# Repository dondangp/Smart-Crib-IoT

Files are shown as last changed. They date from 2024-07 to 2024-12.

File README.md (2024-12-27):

# Smart Crib IoT Abstract

The Smart Crib project integrates hardware and software components to provide users with a seamless and efficient smart home management solution. The system features smart lights, a smart door lock, and a smart fan, all of which can be controlled remotely through a user-friendly mobile application. The application serves as the central interface, allowing users to adjust light brightness, lock and unlock doors via a keypad or app controls, and set fan speeds. Communication between the app and devices is facilitated through an Azure Virtual Machine (VM) server, which processes HTTP control commands and maintains device statuses in real time.

The hardware layer includes an ESP32 microcontroller for the smart door lock & light and a Raspberry Pi Pico for the smart fan, enabling autonomous operations and network communication. The smart door lock features a keypad for local passcode input, providing an additional layer of security. The smart fan allows speed adjustments for customized comfort, while the smart lights support dynamic brightness levels for personalized lighting. By leveraging cloud-based infrastructure and efficient task management on microcontrollers, the Smart Crib project ensures reliable, responsive, and secure smart home control, blending convenience with cutting-edge IoT technology.

# Contributors
-  **Don Dang (Project Lead)**: Created the Smart Home React Native App and Final Poster. Scheduled meetings and assigned tasks for each individual and monitored who completed tasks and attended meetings.
-  **Luis Del Rio**: Created Azure VM server, Smart Light and Smart Doorlock devices. 
-  **Zait Martinez**: Created the hardware, software development, and Printed Circuit Board (PCB) for Smart Fan
- **Ethan Debnath**: Developed Software for IoT App
- **Pranav Pujar**: Developed Software for IoT App

*As of December 03, 2024 - This project will be wrapping up to a finish for Demo Day with no more commits to be made.*

## Features

- **Smart Lights**: Set the brightness of connected smart lights (0-100). Motion detection when someone walks nearby it will turn on the lights.
- **Smart Door Lock**: Lock or unlock the smart door with a simple toggle (Lock/Unlock). Keypad integration to unlock/lock the door lock.
- **Smart Fan**: Adjust the fan speed (Off, Cool, or Heat) to suit your comfort. Has a thermostat attached to it to indicate the degree in fahrenheit and also red and blue LED which will turn on to detect cool or heat mode of the fan.
- **Settings**: Settings to change the Smart Door Lock password.

## Built With

- **React Native**: A popular framework for building mobile applications using React.
- **Axios**: For making HTTP requests to the server.
- **@react-navigation**: For implementing tab-based navigation.
- **@expo/vector-icons**: For using Ionicons in the application.
- **ESP-32**: Smart light & lock hardware/software development
- **Raspberry Pi Pico**: Smart Fan & hardware/software development

# Prerequisites

Before you begin, ensure the following tools and dependencies are installed:

### 1. **Node.js**
   - Install Node.js to manage JavaScript runtime and packages.  
   [Download Node.js](https://nodejs.org/)

### 2. **Xcode**
   - Required for running React Native on iOS devices or emulators.  
   [Download Xcode](https://developer.apple.com/xcode/)

### 3. **npm or yarn**
   - Package managers installed along with Node.js for managing dependencies.

### 4. **Expo CLI**
   - To run the React Native application on mobile devices or emulators. Install via:
     ```bash
     npm install -g expo-cli
     ```

### 5. **Dependencies**
   - Install necessary packages:
     ```bash
     npm install
     npm install axios
     npx expo install expo@latest
     npx expo install --fix
     ```

### 6. **Network Requirement**
   - **Note**: UTA WiFi blocks React Native Expo. Use an alternative WiFi connection.

### 7. **C and Python 3.12.0+**
   - Ensure you have C Version C23 and Python 3.12.0 or higher installed for additional scripts or integrations.

## App Video Demos
[Smart Light & Lock Demo](https://www.youtube.com/watch?v=xLqYLixEVfE)

[Smart Fan Demo](https://www.youtube.com/shorts/cb8d_wNGdIk)

[Final Demo](https://youtu.be/l44uO0imUA0?si=sPAH7cayEWo_ZzFX)

## Demo Images
### Smart Fan Printed Circuit Board
Smart Fan Printed Circuit Board
### Smart Fan
smartfan
### Smart Door Lock Front
doorlock_front
### Smart Door Lock Keypad
doorlock_keypad
### Smart Light (Off)
smart_light_off
### Smart Light (On)
smart_light_on
### Smart Fan Final Printed Circuit Board
smart_fan_pcb

### Smart Fan Back Layout
smart_fan_pcb

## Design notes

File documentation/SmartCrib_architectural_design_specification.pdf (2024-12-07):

## DEPARTMENT OF COMPUTER SCIENCE & ENGINEERING THE

## UNIVERSITY OF TEXAS AT ARLINGTON

## ARCHITECTURAL DESIGN SPECIFICATION CSE

## 4316: SENIOR DESIGN I

# SUMMER 2024

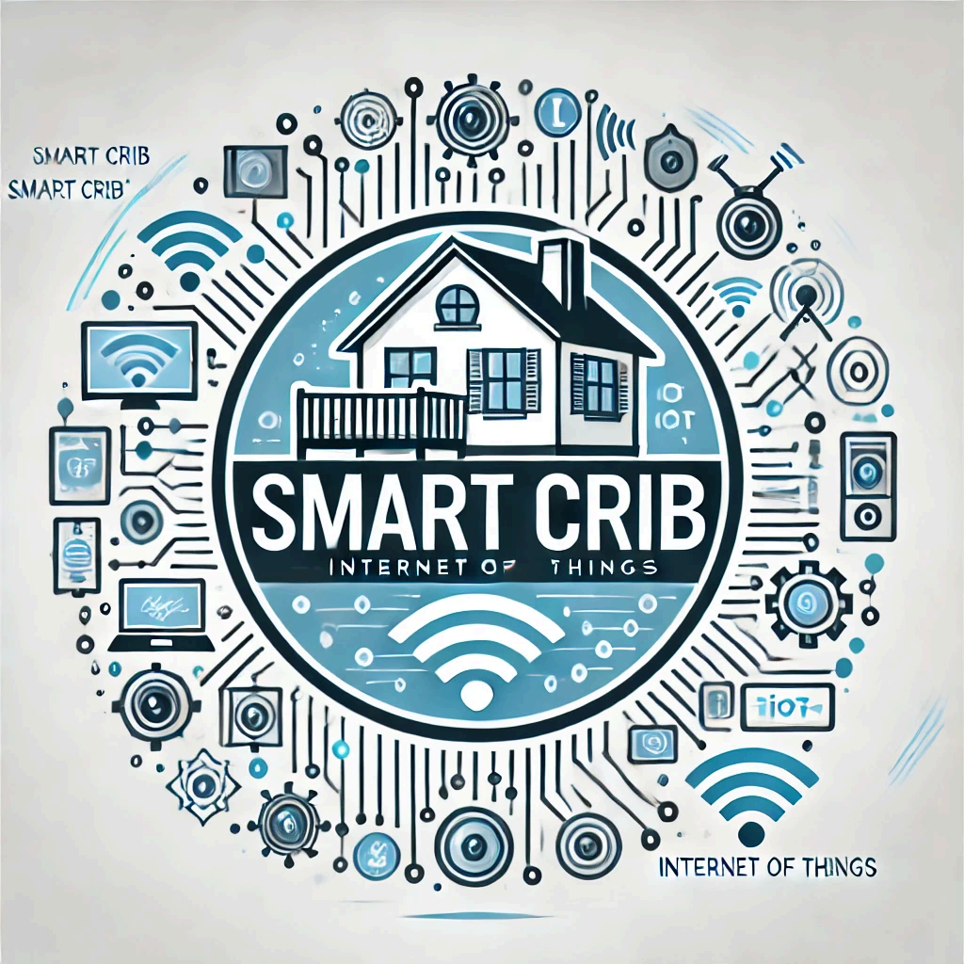
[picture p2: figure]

## INTERNET OF THINGS

# Smart Crib

Don Dang
Luis Del Rio Carrillo
Zait Martinez
Pranav Umakant Pujar
SmartCrib - Summer 2024 | page 1 of 15

REVISION HISTORY

Revision | Date | Author(s) | Description
0.1 | 08/04/2024 | DD, PP, LR | document creation
0.2 | 08/04/2024 | DD, PP | Table of Contents
0.3 | 08/04/2024 | DD | List of Figures
0.4 | 08/04/2024 | DD | List of Tables
1.0 | 08/04/2024 | DD | Introduction
2.0 | 08/05/2024 | DD | System Overview Title
2.1 | 08/05/2024 | DD | Smart Device Layer Description
2.2 | 08/05/2024 | DD | Cloud Server Layer Description
2.3 | 08/05/2024 | PP | App Layer Description
3.0 | 08/05/2024 | PP | Subsystems Definitions & Data Flow
4.1 | 08/05/2024 | LR | Change Title - Smart Device Layer Subsystems
4.1.1 | 08/05/2024 | DD | Assumptions - Hardware
4.1.2 | 08/05/2024 | DD | Responsibilities - Hardware
4.1.3 | 08/05/2024 | DD | Subsystem Interfaces - Hardware
4.2.1 | 08/05/2024 | LR | Assumptions - Software
4.2.2 | 08/05/2024 | LR | Responsibilities - Software
4.2.3 | 08/05/2024 | DD | Subsystem Interfaces - Software
4.3.1 | 08/05/2024 | DD | Assumptions - API Communication
4.3.2 | 08/05/2024 | DD | Responsibilities - Software
4.3.3 | 08/05/2024 | DD | Subsystem Interfaces - DD
5.1.1 | 08/05/2024 | PP | Cloud/Business Logic Layer
6.1.1 | 08/05/2024 | PP | App Layer Subsystems

TABLE OF CONTENTS

4.1 | SUBSYSTEM 1 - HARDWARE
SmartCrib - Summer 2024 | page 2 of 15

4.2 SUBSYSTEM 2 - SOFTWARE

4.3 SUBSYSTEM 3 - API COMMUNICATION

5.1 SUBSYSTEM 1 - AZURE APP SERVICE

6.1 SUBSYSTEM 1 - USER INTERFACE

6.2 SUBSYSTEM 2 - BACKEND COMMUNICATION

6.3 SUBSYSTEM 3 - DEVICE MANAGEMENT

SmartCrib - Summer 2024 | page 3 of 15

LIST OF FIGURES
1. SIMPLE ARCHITECTURAL LAYER DIAGRAM | 5

## 2. SIMPLE DATA FLOW DIAGRAM | 6 3. APP LAYER DIAGRAM | 11

LIST OF TABLES

## 1. LED INTERFACE | 8 2. SERVER INTERFACE | 9 3. API INTERFACE | 10 4. USER INTERFACE | 12 5. BACKEND COMMUNICATION INTERFACE | 13 6. DEVICE MANAGEMENT INTERFACE | 14

SmartCrib - Summer 2024 | page 4 of 15

### 1 INTRODUCTION

We plan to create an IoT system from the ground up. This system will be made up of three main components all of which will be able to communicate remotely. This system will come together to create a home automation system that is capable, expandable, and easy to use.

### 2 SYSTEM OVERVIEW

We have divided our system into three main components based on independence and functionality of individual components. These three components include the application, central server, and the smart devices. Each component can be developed individually then connected for testing and verification later on in the development process. Once basic requirements are set for each component, individual development will begin. After a basic form of the component is completed, api development must begin making sure each component meets each other's api requirements. The goal is for both the application and devices to request data from a centralized server, allowing remote control of smart devices

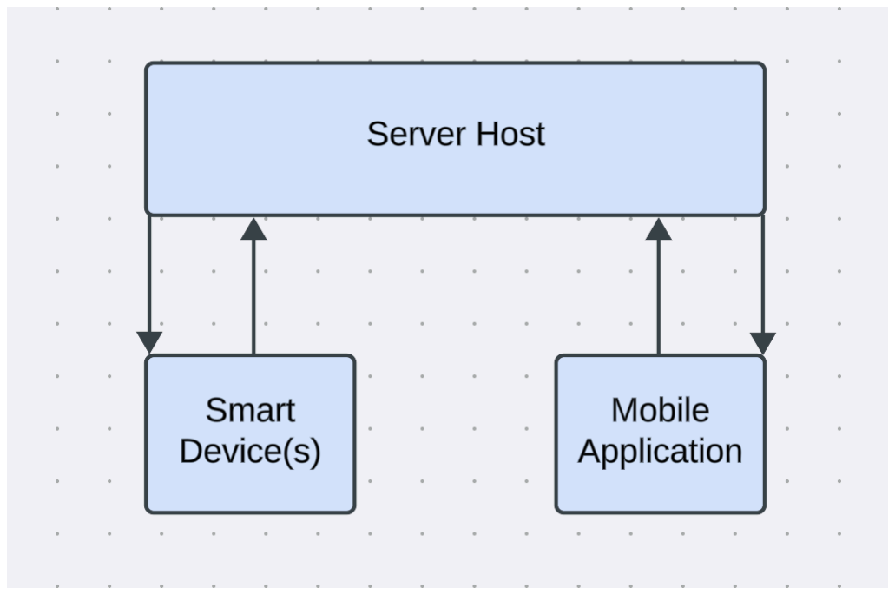
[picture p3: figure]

Figure 1: A simple architectural layer diagram

### 2.1 SMART DEVICE LAYER DESCRIPTION

All smart devices will be composed of at least a ESP32 board capable of communicating through wifi connectivity. This microcontroller will then connect and control a different set of hardware components such as sensors, lights, motors etc. This will compose the physical Smart Device Layer, this layer will be controlled remotely or set automatically depending on its corresponding softwared. Smart devices will allow users to add specific features to their home allowing for easy integration and centralized control of all smart devices within their home. The smart device will be connected to the internet via wifi and request data from a central server. Here it will gather data and update itself and the server accordingly, properly setting its hardware components to reflect users commands.

### 2.2 CLOUD/BUSINESS LOGIC LAYER DESCRIPTION

SmartCrib - Summer 2024 | page 5 of 15

Each layer should be described separately in detail. Descriptions should include the features, functions, critical interfaces and interactions of the layer. The description should clearly define the services that the layer provides. Also include any conventions that your team will use in describing the structure: naming conventions for layers, subsystems, modules, and data flows; interface specifications; how layers and subsystems are defined; etc.
All the smart devices have different states (e.g., color of smart light, brightness of smart light, thermostat temperature, etc) which need to be controllable by the mobile app. These state changes are initiated by a user through the app, which are communicated to the server. The server tracks the changes and when an API request is made by a hardware device to check for state change requests, the response body sent from the Azure server will contain the state change request initiated by the client. The rest is handled by the Hardware Layer.

### 2.3 LAYER Z DESCRIPTION

Each layer should be described separately in detail. Descriptions should include the features, functions, critical interfaces and interactions of the layer. The description should clearly define the services that the layer provides. Also include any conventions that your team will use in describing the structure: naming conventions for layers, subsystems, modules, and data flows; interface specifications; how layers and subsystems are defined; etc.
The App layer contains various UI features to allow for users to make changes in the state of the smart hardware devices present. These functions are enabled through a user-friendly React Native Mobile App interface. This app can send HTTP POST requests to the Azure server to initiate state changes in hardware as requested by the user.

### 3 SUBSYSTEM DEFINITIONS & DATA FLOW

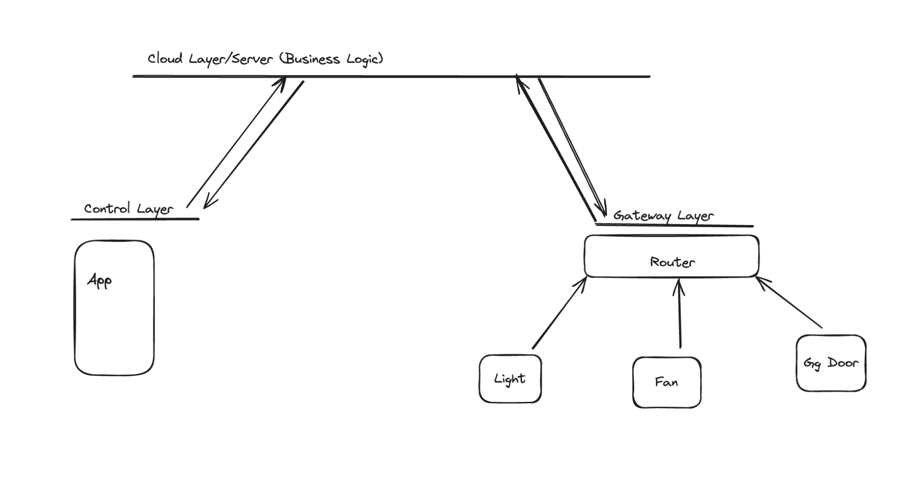
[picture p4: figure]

Figure 2: A simple data flow diagram

SmartCrib - Summer 2024 | page 6 of 15

### 4 SMART DEVICE LAYER SUBSYSTEMS

In this section, the layer is described in some detail in terms of its specific subsystems. Describe each of the layers and its subsystems in a separate chapter/major subsection of this document. The content of each subsystem description should be similar. Include in this section any special considerations and/or trade-offs considered for the approach you have chosen.

For this example I will be using our Smart Light Device which is the first device we will integrate into our system
The Smart Light Device will have its hardware subsystem; these components give the device functionality, it will have a software subsystem to collect and control its hardware components accordingly, and lastly the api/communication subsystem which will be required to communicate necessary data back and forth between other layers.

### 4.1 SUBSYSTEM 1 HARDWARE

For the hardware portion of the device a ESP32 microcontroller will be physically connected to different components, for our Smart Light Device these components include LED module, Motion Sensor Module, and a Light Sensor Module. The ESP32 has the capability to power, receive and send signals to all of these components. These components capture raw data and send it back to the microcontroller which decides what to do with this data and can also give new instructions to components. The microcontroller will use this data to give other layers feedback about itself and its environment, the LED’s will reflect these commands accordingly.

### 4.1.1 ASSUMPTIONS

The assumptions made are that all our devices will use the same main microcontroller ( ESP32 ) but the components connected will vary from device to device, All hardware components will be physically connected to GPIO pins for input and output interfaces

### 4.1.2 RESPONSIBILITIES

The responsibilities of this subsystem is to reflect commands and automatic settings, hardware will be what users get to see and interact with when it comes to home automation ( aside from application ). For each user command there must be a hardware component to reflect the command accordingly.

### 4.1.3 SUBSYSTEM INTERFACES

Interface between ESP32 and LED Module
Interface between ESP32 and Motion Sensor Interface between ESP32 and Light Sensor

Table 1: LED interfaces

SmartCrib - Summer 2024 | page 7 of 15

ID | Description | Inputs | Outputs
SD1 | ESP32 to LED MODULE | LED command | Color change Brightness Change On/Off
SD2 | Motion Sensor to ESP32 | Sense Motion | Corresponding LED command
SD3 | Motion Sensor to ESP32 | Sense Light | Brightness change Command

### 4.2 SUBSYSTEM 2 SOFTWARE

Software will be embedded into every smart device to control the hardware modules it has been given access to. Our Smart Light Device will include software that communicates with the LED module, and sensor modules. Corresponding libraries will be utilized to ensure communication compatibility between components is fully functional. Data collection will also be customized and collected accordingly through software such as when the last time we sensed motion, the amount of light in the room, the current state of the LED, the color, and brightness. This will all later be used to send feedback to other layers in the system. Software will also be in charge of adjusting and updating hardware components according to changes in its environment or changes requested by other layers.

### 4.2.1 ASSUMPTIONS

Software will differ from device to device since data collection will be different and so will outputs and inputs. All software in Smart Devices will be written in the same language and format.

### 4.2.2 RESPONSIBILITIES

Software must collect useful data available and react in correlation with data.

### 4.2.3 SUBSYSTEM INTERFACES

Interface between input data from hardware and output signals

Interface between server Data and current hardware status data

Table 2: Server interface

SmartCrib - Summer 2024 | page 8 of 15

ID | Description | Inputs | Outputs
US1 | Server data update | Request Update from Server | Process data update hardware status
US2 | Current Device Status Update | Request Update from Server | Server Update current hardware status

### 4.3 SUBSYSTEM 3 API / COMMUNICATION

The ESP32 board will be in charge of communicating with our server constantly in order to keep the server up to date with current data, as well as keeping itself updated and aligned with user requests. Wifi connection is crucial as it is the means through which we will be communicating. Http requests will be made to the server a couple times a minute ensuring we are always updated, however responsiveness is not a high priority therefore we see no issue with having a small delay in reaction times when it comes to updating device status when users request or command a change/adjustment. The Smart Device will only communicate with the server who will be available at all times. Every time they communicate they will both transfer data, the device will let the server know if any adjustments or commands have been made by a user and the device will let it know its current state allowing the device to compare this data and adjust accordingly, this system will allow Smart Devices to be controlled remotely from anywhere with internet access.

### 4.3.1 ASSUMPTIONS

All layers will communicate using http request in a server client style model. They will have internet access at all times and available for one another at all times.

### 4.3.2 RESPONSIBILITIES

This subsystem is responsible for communicating relevant data with other layers as well as gathering relevant data from other layers in order to allow embedded software to control hardware components accordingly.

### 4.3.3 SUBSYSTEM INTERFACES

Interface between Server and Device

Table 2: Subsystem interfaces

SmartCrib - Summer 2024 | page 9 of 15

ID | Description | Inputs | Outputs
SR1 | Device makes Server Request | Update Request | Update Server and Update Device

### 5 CLOUD/ BUSINESS LOGIC LAYER SUBSYSTEMS

In this section, the layer is described in some detail in terms of its specific subsystems. Describe each of the layers and its subsystems in a separate chapter/major subsection of this document. The content of each subsystem description should be similar. Include in this section any special considerations and/or trade-offs considered for the approach you have chosen.
This layer is responsible for being an always-on point of contact for the client (mobile application) as well as the individual hardware systems within the hardware layer (layer 1). It should facilitate one-way command transmission from the client to the respective hardware device.

### 5.1 SUBSYSTEM 1 - AZURE APP SERVICE

The first and only subsystem is “Azure App Service”. This is a PaaS service that will allow us to permanently host a server on the cloud. It will also allow the various hardware devices as well as the mobile pap client to interact with it through API/HTTP requests.

### 5.1.1 ASSUMPTIONS

We assume the following:
1. The costs of this Azure cloud service will be reasonably within the $200 sign-up credit offered for the new account.
2. The API connection between the backend of the mobile app and the server hosted in the cloud will be reasonably fast in order to show functionality in real time.
3. The ESP32 chips that are installed on the smart devices will be able to connect to the server via API/HTTP requests.

### 5.1.2 RESPONSIBILITIES

Handle API requests from the backend of the client app as well as the individual hardware devices. Execute business logic in order to ensure state changes in the individual devices happen as per the client’s request.

### 5.1.3 SUBSYSTEM INTERFACES

Table 3: API interfaces

ID | Description | Inputs | Outputs
C1 | Client (Mobile App) | Payload from API Request | API Response
C2 | Individual Hardware Subsystems | Payload from API Request | API Response
SmartCrib - Summer 2024 | page 10 of 15

### 6 APP LAYER SUBSYSTEMS

The SmartCrib React Native app layer consists of several key subsystems that collectively provide a seamless user experience for home automation. The User Interface (UI) subsystem is responsible for rendering screens and handling user interactions, while the Backend Communication subsystem manages data exchange with the server. The Device Management subsystem enables integration, control, and monitoring of connected devices. Together, these subsystems ensure secure, efficient, and user-friendly control of smart home devices.

### 6.1 SUBSYSTEM 1: USER INTERFACE

The User Interface (UI) subsystem is responsible for all aspects of user interaction with the SmartCrib app. This includes rendering screens, handling user inputs, and displaying data from connected devices. The UI provides an intuitive and seamless experience, allowing users to easily control and monitor their smart home devices. It serves as the front-end layer that communicates with the backend services to fetch and display data, as well as to send user commands to the devices.

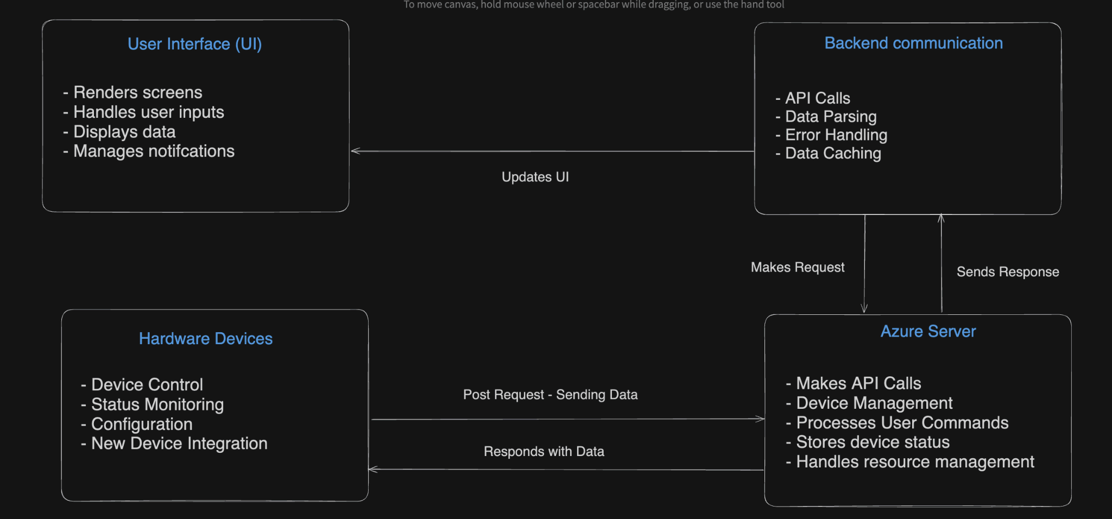
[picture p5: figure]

Figure 3: App Layer Diagram

### 6.1.1 ASSUMPTIONS

- The UI subsystem assumes that users have a basic understanding of mobile apps and can navigate through typical app interfaces.
- The UI is designed to interact with the device's native features, such as touch input and notifications.
- It is assumed that the devices running the app will have internet connectivity to communicate with the backend systems.
- Interfaces and interactions with the backend server are stable and will not undergo frequent changes.
SmartCrib - Summer 2024 | page 11 of 15

### 6.1.2 RESPONSIBILITIES

- Rendering Screens: The UI subsystem is responsible for rendering the various screens of the app, such as the home screen, device control screen, and settings.
- User Interaction: It handles all user interactions, including button presses, gestures, and navigation between different screens.
- Displaying Data: Fetches and displays data from the backend, such as the status of connected devices.
- User Notifications: Manages notifications to alert users about important events or updates from the SmartCrib system.

### 6.1.3 SUBSYSTEM INTERFACES - USER INTERFACE

Table 4: User Interface

ID | Description | Inputs | Outputs
UI-1 | Main Navigation Interface | User gestures, commands | Screen transitions
UI-2 | Device Status Display Interface | Device status data | Visual status indicators
UI-3 | User Notification Interface | Backend notifications | App notifications
UI-4 | Settings Configuration Interface | User Input | Updated settings data

### 6.2 SUBSYSTEM 2: BACKEND COMMUNICATION

The Backend Communication subsystem manages all interactions between the SmartCrib app and the backend server. It handles API requests to fetch and send data, ensuring that the app remains synchronized with the backend. This subsystem is crucial for maintaining the flow of information between the app and the devices, enabling users to control their smart home devices and receive real-time updates.

### 6.2.1 ASSUMPTIONS

- Assumes stable and reliable internet connectivity to communicate with backend servers.
- The backend APIs follow RESTful principles and provide consistent and predictable responses.
- Authentication and authorization mechanisms are securely implemented on the backend.
SmartCrib - Summer 2024 | page 12 of 15

### 6.2.2 RESPONSIBILITIES

- API Calls: Makes HTTP requests to the backend server to fetch and send data.
- Data Parsing: Parses JSON responses from the server and converts them into usable data structures within the app.
- Error Handling: Manages errors related to network issues, server downtime, or invalid responses.
- Data Caching: Implements caching mechanisms to store frequently accessed data and reduce the number of network requests.

### 6.2.3 BACKEND COMMUNICATION INTERFACE

ID | Description | Inputs | Outputs
BC-1 | Device Control API Interface | User commands | Server responses
BC-2 | Device Status Fetch Interface | API requests | Device status data
BC-3 | User Authentication Interface | Login credentials | Authentication tokens
BC-4 | Notification Fetch Interface | API requests | Notification data

### 6.3 SUBSYSTEM 3: DEVICE MANAGEMENT

The Device Management subsystem is responsible for the integration and control of smart home devices within the SmartCrib ecosystem. This subsystem allows users to add new devices, configure existing ones, and manage their operations. It ensures that devices are properly connected and can be controlled through the app, providing a seamless user experience.

### 6.3.1 ASSUMPTIONS

- Assumes that the devices being controlled (e.g., lights, garage doors) are compatible with the SmartCrib system and follow the expected communication protocols.
- Assumes stable communication between the app and the devices, either directly or via the backend server.

### 6.3.2 RESPONSIBILITIES

- Device Control: Sends commands to devices to change their state (e.g., turn lights on/off).
- Device Status Monitoring: Continuously monitors and fetches the current status of connected devices.
- Device Configuration: Allows users to configure device settings such as names, icons, and operational parameters.
- Integration with New Devices: Provides mechanisms to integrate and manage new devices added to the SmartCrib system.
SmartCrib - Summer 2024 | page 13 of 15

### 6.3.3 DEVICE MANAGEMENT INTERFACE

ID | Description | Input | Output
DM-1 | Device Command Interface | User commands | Device actions
DM-2 | Device Status Interface | Device status data | Displayed status
DM-3 | Device Configuration Interface | Configuration data | Updated device settings
DM-4 | New Device Integration Interface | Device information | Integrated device data
SmartCrib - Summer 2024 | page 14 of 15

REFERENCES
ip_admin. “Unpacking IoT Architecture: Layers and Components Explained.” Device Authority,

16 Sept. 2023,

deviceauthority.com/unpacking-iot-architecture-layers-and-components-explained

/#:~:text=IoT%20architecture%20is%20an%20organised. (http://deviceauthority.com/unpacking-iot-architecture-layers-and-components-explained/)

“LibGuides: Internet of Things (IoT): Architecture of Internet of Things.” Libguides.com, 2020,

bowiestate.libguides.com/internet_of_things_iot/architecture_of_Internet_of_thin

gs. Accessed 6 Aug. 2024.

Simmons, Adam. “Internet of Things (IoT) Architecture: Layers Explained.” Dgtl Infra, 14 Nov.

2022, dgtlinfra.com/internet-of-things-iot-architecture/.

SmartCrib - Summer 2024 | page 15 of 15

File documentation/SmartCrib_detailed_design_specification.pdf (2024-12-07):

## DEPARTMENT OF COMPUTER SCIENCE & ENGINEERING

## THE UNIVERSITY OF TEXAS AT ARLINGTON

## DETAILED DESIGN SPECIFICATION

# CSE 4317: SENIOR DESIGN II FALL 2024

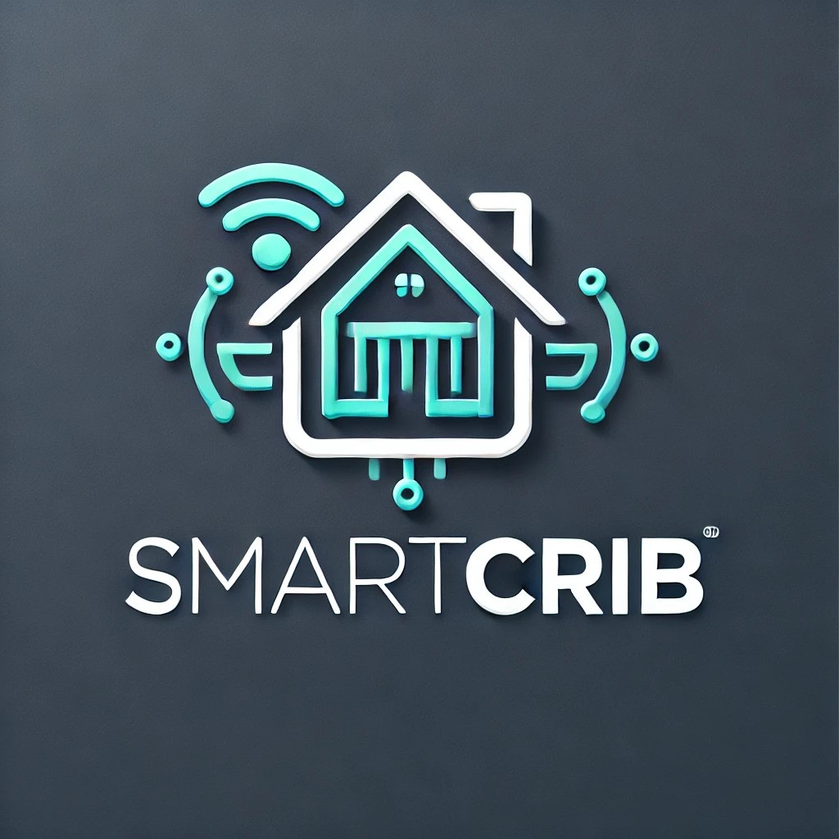
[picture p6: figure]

## SMART CRIB IOT TEAM

## SMART CRIB

DON DANG
LUIS CARRILLO
ZAIT MARTINEZ
PRANAV PUJAR
Smart Crib IoT Team - Fall 2024 | page 1 of 28

REVISION HISTORY

Revision | Date | Author(s) | Description
0.1 | 10.12.2024 | DD | document creation
0.2 | 10.14.2024 | DD, LC | complete draft
0.3 | 10.15.2024 | DD | updated logo
1.1 | 10.15.2024 | DD, ZM, PP | imported subsystem images
1.1 | 10.15.2024 | DD, LC | revised layer subsystems
1.0 | 10.18.2024 | DD, LC | official release

CONTENTS

1 Introduction | 5
2 System Overview | 5
3 Application Layer Subsystems | 6
4 Server Layer Subsystems | 15
5 Device Layer Subsystems | 18
6 Appendix A | 25
Appendix A: Schematic for Smart Light Subsystem | 25
Appendix C: Circuit Schematic of the Smart Lock Subsystem | 26
Appendix B: Circuit Schematic for Smart Fan Subsystem | 27

LIST OF FIGURES

1 | System Architecture | | 6
2 | Smart Light Subsystem Architecture Diagram | | 8
3 | Smart Doorlock Subsystem Architecture Diagram | | 11
4 | Smart Fan Device Subsystem Diagram | | 13
5 | Request Handler Subsystem Diagram | | 16
6 | Smart Light Device Subsystem Diagram | | 19
7 | Smart Lock Device Subsystem Diagram | | 21
8 | Smart Fan Device Subsystem Diagram | | 23
9 | Circuit Schematic for the Smart Light Subsystem | | 25
10 | Circuit Schematic for the Smart Lock Subsystem | | 26
11 | Circuit Schematic for the Smart Fan Subsystem | | 27

### 1 INTRODUCTION

The Smart Crib application is an IoT-based smart home management system designed to provide users with control over various connected home devices, including smart lights, door locks, and fans. The application integrates with an ESP32 and Raspberry Pi microcontroller-based setup and communicates with a server to manage and monitor the status of these devices in real-time. The product aims to enhance the convenience for home environments by offering intuitive controls via a mobile interface.

### 2 SYSTEM OVERVIEW

The Smart Crib application architecture is designed with a layered approach, ensuring efficient communication between the mobile interface, the server, and the IoT devices. The system’s data flow diagram, as outlined in the architectural specification, details three key layers: the Application Layer, the Server Layer, and the Device Layer. The Application Layer is the front-end interface developed using React Native. It provides users with a seamless and intuitive way to interact with their connected devices, such as adjusting light brightness, managing fan speed, and controlling door locks. The client sends user commands as HTTP requests to the server and displays device statuses based on the server’s responses.

The Server Layer acts as an intermediary between the client and the devices. It is built using a Python-based HTTP server that listens for and processes requests from the client layer. The server updates device states accordingly and sends relevant information back to the client. It is designed to handle multiple requests efficiently using a multi-threaded approach, ensuring that device operations and data consistency are maintained. Lastly, the Device Layer comprises the IoT devices controlled by an ESP32 microcontroller. These devices include smart lights, fans, and door locks, which receive instructions from the server and periodically report their status. The microcontroller translates the server’s instructions into physical actions while keeping the system synchronized by sending back status updates. This multi-layered architecture ensures a responsive and reliable smart home experience for users.

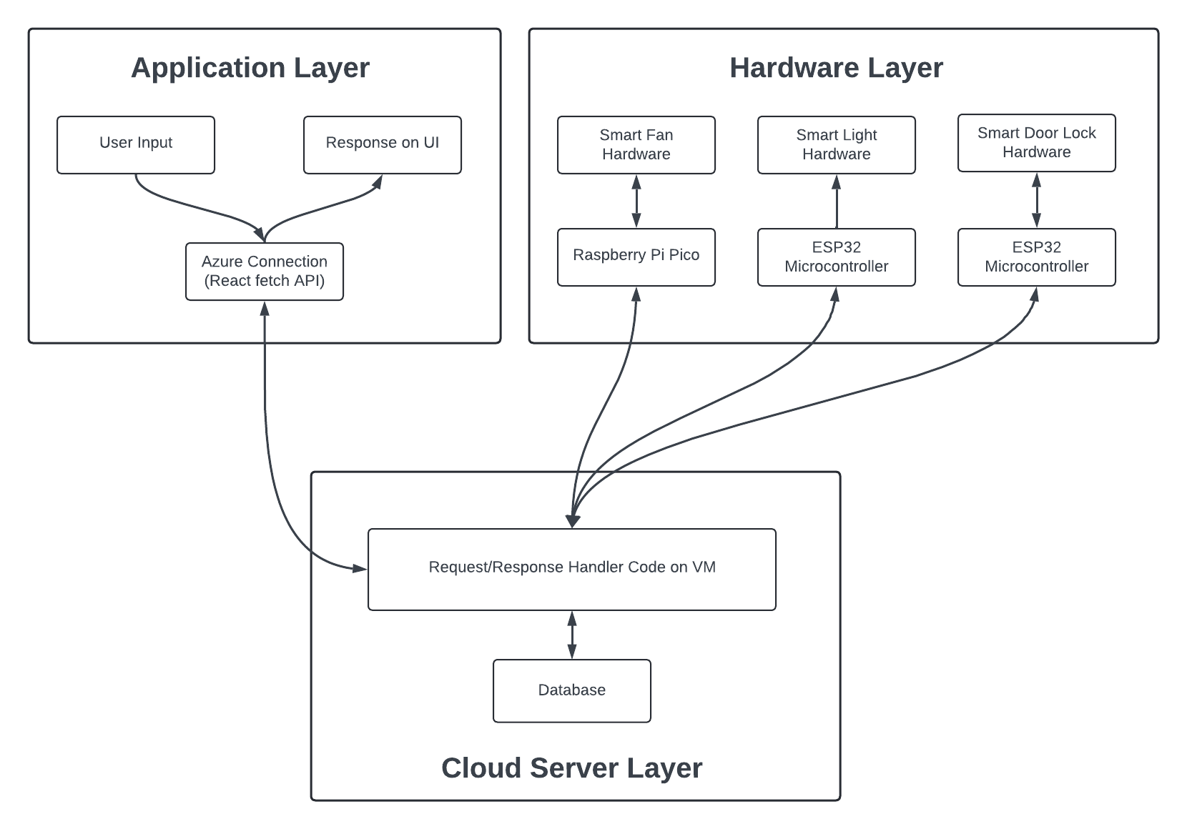
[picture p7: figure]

Figure 1: System Architecture

### 3 APPLICATION LAYER SUBSYSTEMS

The Application Layer of the Smart Crib system is responsible for providing users with an interface to interact with their smart home devices, such as smart lights, door locks, and fans. This layer is purely software-based and does not rely on specific hardware components. It is implemented using JavaScript and React Native, which is a popular framework for building cross-platform mobile applications. This approach allows the app to be deployed on both iOS and Android devices, ensuring a broad user base without needing to manage separate codebases.

The application utilizes several key frameworks and dependencies to enhance its functionality. React Native serves as the primary framework for developing the mobile interface, providing components and APIs for building user interfaces and handling mobile-specific functionalities like navigation and gesture handling. The navigation system is created using React Navigation, which facilitates a tab-based structure that allows users to switch easily between different device controls, such as Lights, Door lock, and Fan. Axios, an HTTP client, is used for making API requests from the application to the server, ensuring smooth and efficient data exchange. Additionally, Ionicons is used to add icons in the tab navigation, enhancing the visual appeal and providing users with intuitive navigation cues.

In terms of compatibility, the application is designed to work on both iOS and Android mobile operating systems, providing flexibility and accessibility for various types of mobile devices. The UI design focuses on simplicity and responsiveness, with a tab-based navigation system that lets users switch between device controls seamlessly. The app displays current device statuses and allows users to control various devices with minimal input, providing a user-friendly and efficient interface.

The Application Layer communicates with the server layer using HTTP protocols. It sends requests via Axios, and the server responds with updates based on user interactions, enabling real-time control of smart home devices. The network communication is optimized to ensure low latency, offering users a responsive and seamless experience. This layered approach ensures that the Application Layer integrates effectively with the rest of the system, providing a consistent and reliable experience across different mobile platforms.

### 3.1 APPLICATION LAYER HARDWARE

The Application Layer of the Smart Crib system is primarily software-based and does not involve any specific hardware components directly. This layer operates as a mobile application running on users’ smartphones or tablets, which serves as the primary interface for controlling and monitoring smart home devices. The devices that can run the application include iOS and Android smartphones, tablets, and other mobile devices capable of supporting React Native applications. The hardware requirements for these devices are minimal, as the application is designed to be lightweight, ensuring compatibility across a wide range of devices.

### 3.2 APPLICATION LAYER OPERATING SYSTEM

The Application Layer of the SmartCrib system operates on mobile devices running either iOS or Android operating systems. The application is developed using React Native, a cross-platform framework that allows the same codebase to be used for both operating systems, ensuring consistent functionality and user experience across devices.

On iOS, the application is compatible with devices running iOS 12.0 or later, while on Android, it supports versions from Android 5.0 (Lollipop) onwards. React Native’s integration with native modules allows the application to utilize device capabilities such as network communication and sensors efficiently on both platforms.

No additional operating systems are required specifically for this layer beyond the mobile OS versions mentioned. The application is designed to be lightweight and compatible across a wide range of mobile devices to maximize accessibility and ensure broad user adoption.

### 3.3 APPLICATION LAYER SOFTWARE DEPENDENCIES

The Application Layer of the Smart Crib system relies on several software dependencies to enable its functionality and ensure a smooth user experience. The primary framework used is React Native, which facilitates the development of a cross-platform mobile application compatible with both iOS and Android devices. Within React Native, additional libraries and packages are utilized to enhance the application’s capabilities.

To manage navigation between screens and components, the application uses React Navigation, which provides a seamless and intuitive experience for users by enabling tab navigation. This allows users to switch between different device controls like lights, door locks, and fans effortlessly. For network communication, Axios is used to handle HTTP requests between the mobile application and the backend server. This dependency allows the app to send user commands, such as adjusting brightness, and to receive updates on device statuses.

Expo is another crucial dependency, simplifying the development, testing, and deployment process across multiple platforms. It ensures compatibility with different devices, enabling quick feature testing and deployment. To enhance the visual appeal of the application, React Native Vector Icons is utilized for adding icons that represent various controls and navigation elements, providing a user-friendly interface. Finally, Prop Types is used for type-checking props passed to components, ensuring data consistency and stability within the application.

These dependencies collectively support the functionality, user interface, and network communication of the Smart Crib mobile application, ensuring that it operates efficiently and seamlessly across various mobile platforms.

### 3.4 LIGHT CONTROL SUBSYSTEM

The Smart Crib application is the Smart Lights Control Subsystem, which is a combination of both hardware and software components designed to provide users with remote control over the lighting system within their smart home. This subsystem allows users to adjust the brightness of lights via the mobile application, ensuring convenience and energy efficiency.

On the software side, the Smart Lights Control Subsystem is managed through the mobile application interface, developed using React Native. The mobile app sends user inputs as HTTP POST requests to the backend server, which then relays the commands to the ESP32. The server is responsible for processing these requests, managing the state of the lights, and ensuring real-time feedback is communicated back to the user.

This subsystem provides seamless integration between the user interface, the server, and the smart light hardware, allowing for efficient and responsive control over the lighting in a smart home environment.

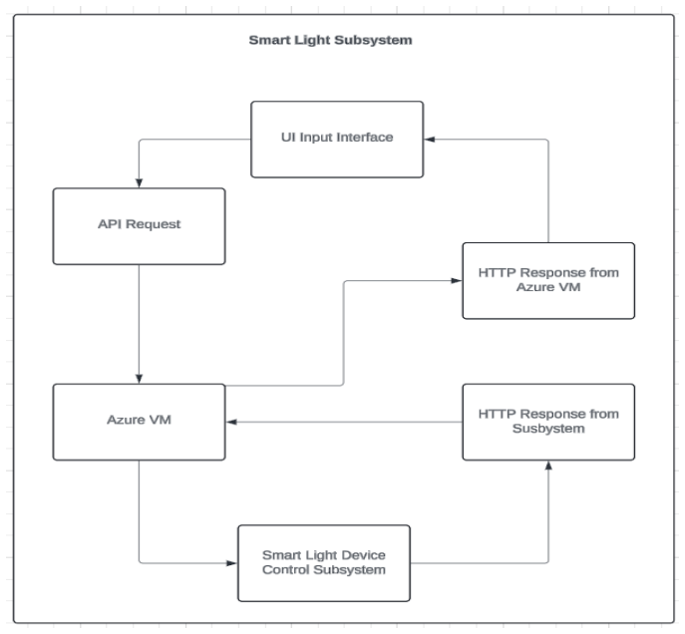
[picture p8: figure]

Figure 2: Smart Light Subsystem Architecture Diagram

### 3.4.1 LIGHT CONTROL SUBSYSTEM HARDWARE

The hardware component of this subsystem consists of smart light modules connected to an ESP32 microcontroller. The ESP32 is responsible for receiving commands from the server and adjusting the light’s brightness levels accordingly. The microcontroller translates the digital signals sent by the application into physical actions, such as dimming or brightening the lights.

### 3.4.2 LIGHT CONTROL SUBSYSTEM OPERATING SYSTEM

The Smart Lights Control Subsystem within the Smart Crib application relies on the ESP32 microcontroller, which runs on a real-time operating system (RTOS) called FreeRTOS. FreeRTOS is an opensource operating system specifically designed for embedded devices like the ESP32, providing lowlatency and reliable task management crucial for IoT applications.

FreeRTOS allows the ESP32 to efficiently manage multiple tasks simultaneously, such as receiving commands from the server, adjusting the brightness of the lights, and sending status updates back to the server. The lightweight and efficient nature of FreeRTOS makes it an ideal choice for the resourceconstrained environment of the ESP32, ensuring quick response times and seamless control over the lighting system.

### 3.4.3 LIGHT CONTROL SUBSYSTEM SOFTWARE DEPENDENCIES

The Smart Lights Control Subsystem within the Smart Crib application relies on several software dependencies to manage the functionality of the ESP32 microcontroller and ensure seamless communication and control over the lighting system.

Key libraries used include the Adafruit NeoPixel library, which is essential for controlling LED strips and individual lights connected to the ESP32. This library provides functions for adjusting brightness levels, setting colors, and creating lighting effects. The WiFi library is also utilized, enabling the ESP32 to connect to the network and communicate with the Smart Crib server. For handling HTTP requests and responses, the HTTPClient library is implemented, allowing the ESP32 to receive commands from the server and send back status updates effectively.

Additionally, ArduinoJson is used to parse JSON data sent between the server and the ESP32, ensuring accurate interpretation and processing of commands related to light adjustments. These software libraries are integrated within the ESP32’s development environment, programmed using the Arduino IDE, which provides a comprehensive platform for coding, testing, and debugging the firmware controlling the smart lights. These dependencies are essential for the subsystem to function efficiently, ensuring that the lights respond promptly to user commands via the mobile interface.

### 3.4.4 LIGHT CONTROL SUBSYSTEM PROGRAMMING LANGUAGES

The Smart Lights Control Subsystem in the Smart Crib application is primarily programmed using C/C++, which is the standard for developing firmware on microcontroller platforms like the ESP32. This language choice is due to its efficiency and low-level hardware access, making it ideal for controlling components such as LEDs and managing network communication directly through the microcontroller’s interfaces.

C/C++ is utilized to integrate essential libraries such as Adafruit NeoPixel for LED control and WiFi for network connectivity, ensuring the ESP32 can interact with the Smart Crib server. The code is developed and compiled using the Arduino IDE, which supports C/C++ and provides a user-friendly environment for building and deploying firmware onto the microcontroller. This combination of languages and development tools allows precise control over the lighting hardware, enabling real-time response to user inputs from the Smart Crib mobile app.

### 3.4.5 LIGHT CONTROL SUBSYSTEM DATA STRUCTURES

In the Smart Lights Control Subsystem of the Smart Crib application, data is transmitted from the ESP32 microcontroller to the server using JSON packets, which provide a lightweight and structured format for communication. Each packet contains an identifier (id) for the microcontroller, a device field indicating the type (where 1 represents the light component), and a brightness value ranging from 0 (off) to 100 (maximum brightness) that reflects the light’s current setting. Additionally, a timestamp is included to log when the packet is sent, aiding in tracking and debugging. This structured approach ensures consistent and efficient communication between the light device and the server, enabling accurate control and monitoring within the Smart Crib system.

### 3.4.6 LIGHT CONTROL SUBSYSTEM DATA PROCESSING

The Light Control Subsystem in the Smart Crib application employs a straightforward data processing algorithm to adjust light brightness levels based on user inputs received through the mobile application. The algorithm first validates the brightness value, ensuring it falls within the acceptable range of 0 to 100. Once validated, the system sends the brightness value, along with the device identifier, to the ESP32 microcontroller via a JSON packet. The microcontroller processes this data and adjusts the PWM (Pulse Width Modulation) signal accordingly, altering the light intensity in real-time. The system uses a PID (Proportional-Integral-Derivative) control mechanism to smooth out transitions and prevent abrupt changes in brightness, ensuring a comfortable user experience. This algorithm not only allows precise control of lighting but also ensures energy efficiency by adjusting the brightness based on user preferences and predefined settings.

### 3.5 DOOR LOCK CONTROL SUBSYSTEM

The Door lock Control Subsystem utilizes an ESP32 microcontroller connected to an electronic lock mechanism. The electronic lock operates using a solenoid or a motorized actuator to engage or disengage the lock based on the user’s input. This hardware setup is compact and designed to fit within standard door lock assemblies, allowing for easy installation and integration with existing home setups.

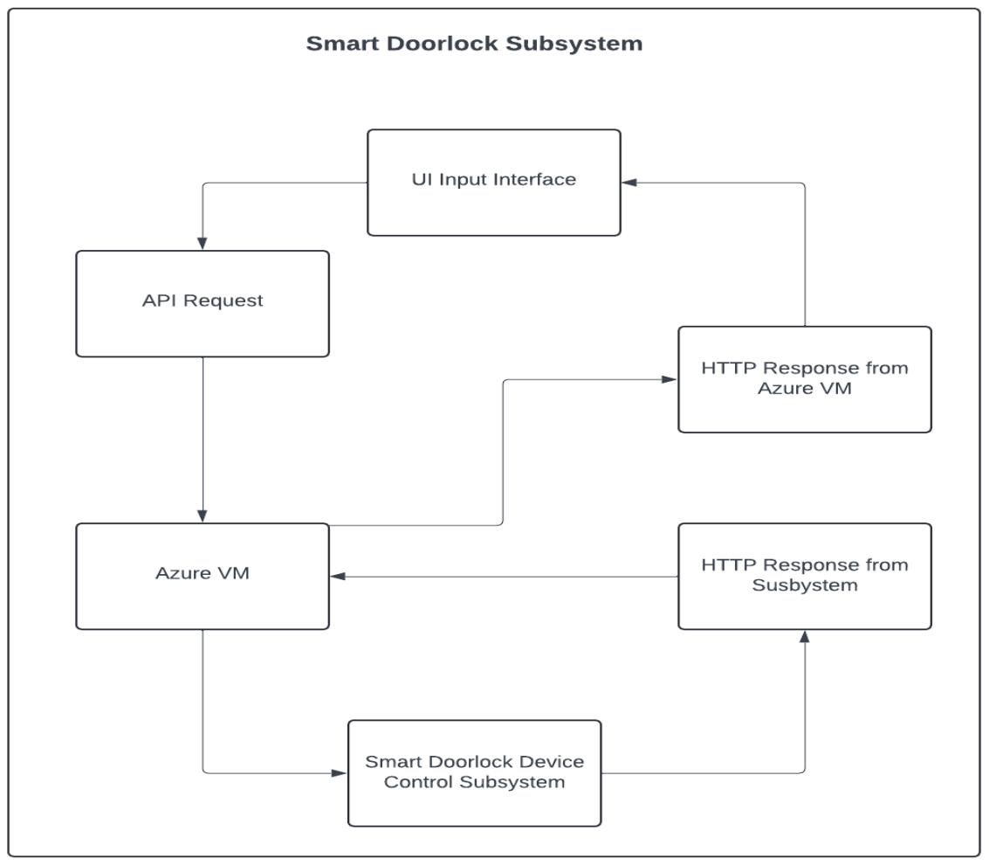
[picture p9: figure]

Figure 3: Smart Doorlock Subsystem Architecture Diagram

### 3.5.1 DOOR LOCK SUBSYSTEM HARDWARE

The Door lock Control Subsystem utilizes an ESP32 microcontroller connected to an electronic lock mechanism. The electronic lock operates using a solenoid or a motorized actuator to engage or disengage the lock based on the user’s input. This hardware setup is compact and designed to fit within standard door lock assemblies, allowing for easy installation and integration with existing home setups.

### 3.5.2 DOOR LOCK SUBSYSTEM OPERATING SYSTEM

The subsystem does not have a separate operating system as it relies on the real-time capabilities of the ESP32 microcontroller. The microcontroller runs its firmware, developed using the Arduino framework, which facilitates direct hardware control and communication with the server.

### 3.5.3 DOOR LOCK SUBSYSTEM SOFTWARE DEPENDENCIES

The Door lock Control Subsystem software depends on several libraries, including the WiFi.h library for establishing a wireless connection with the home network, HTTPClient.h for communicating with the Smart Crib server, and ArduinoJson.h for parsing and creating JSON packets to manage data exchange efficiently. Additionally, the Servo.h library is used for controlling the motorized actuator that locks or unlocks the door.

### 3.5.4 DOOR LOCK SUBSYSTEM PROGRAMMING LANGUAGES

The subsystem is programmed using C/C++, specifically leveraging the Arduino framework. This choice allows for real-time, low-level hardware interaction essential for the control of the electronic lock components and communication modules of the ESP32 microcontroller.

### 3.5.5 DOOR LOCK SUBSYSTEM DATA STRUCTURES

The Door lock Control Subsystem uses a simple JSON data structure for communication between the server and the microcontroller. The structure includes fields for id, device, and door lock status (0 for unlocked and 1 for locked). This packet is transmitted from the server to the ESP32, which interprets the command and adjusts the lock mechanism accordingly.

### 3.5.6 DOOR LOCK SUBSYSTEM DATA PROCESSING

The data processing algorithm for the Door lock Control Subsystem checks incoming JSON packets for the door lock field value, which determines whether the door should be locked or unlocked. The ESP32 microcontroller receives this information and activates the actuator accordingly. To prevent unauthorized access or incorrect operations, the system validates the command using pre-configured security protocols, ensuring that the door lock status can only be modified by authenticated user requests. If the lock state changes, the system sends a status update back to the server, maintaining synchronization with the mobile application.

### 3.6 SMARTFAN CONTROL SUBSYSTEM

The Smart Fan Subsystem is designed as an IoT-controlled piece of hardware that manages the speed and operation of a connected fan. It operates autonomously or through user commands received from the Smart Crib application. At its core, the subsystem uses an ESP32 microcontroller, which serves as the central processing unit for controlling fan speed and monitoring environmental conditions like temperature and humidity through sensors.

The subsystem communicates with the Smart Crib server via Wi-Fi, sending sensor data and receiving user commands to adjust the fan speed using Pulse Width Modulation (PWM) techniques. The microcontroller runs firmware built with the Arduino framework, ensuring real-time responsiveness and seamless integration with the overall system. This setup allows the Smart Fan Subsystem to act as an intelligent component within the Smart Crib ecosystem, providing efficient and customizable air circulation based on environmental feedback or user preferences.

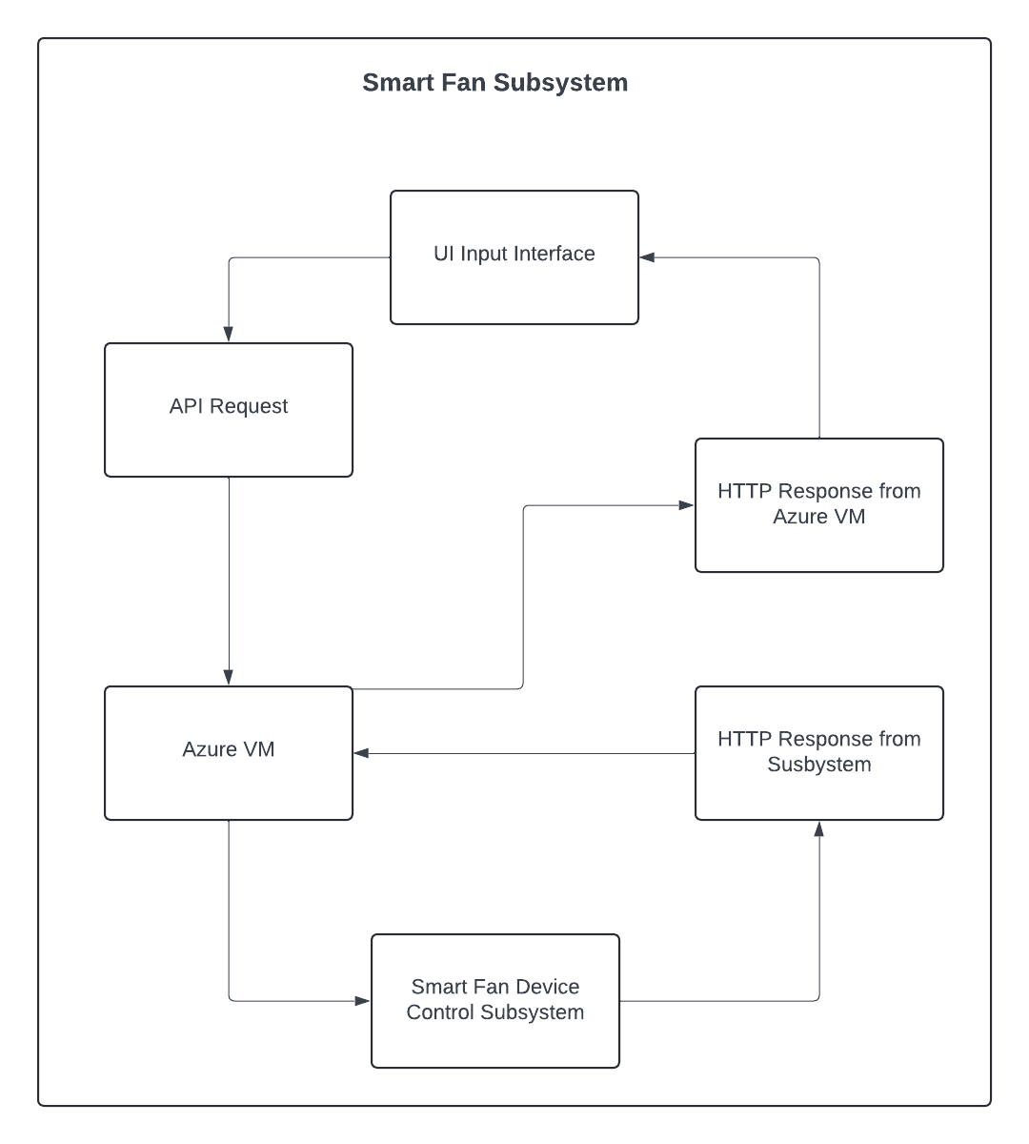
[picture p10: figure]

Figure 4: Smart Fan Device Subsystem Diagram

### 3.6.1 SMART FAN SUBSYSTEM HARDWARE

The Smart Fan Subsystem uses an ESP32 microcontroller connected to a variable-speed fan via a relay module or a Pulse Width Modulation (PWM) motor driver. The ESP32 adjusts the fan speed based on user input or environmental conditions. Sensors, such as DHT11 or DHT22, are connected to monitor temperature and humidity levels, providing the system with real-time environmental data.

### 3.6.2 SMART FAN SUBSYSTEM OPERATING SYSTEM

The Smart Fan Subsystem runs on the ESP32 microcontroller without a dedicated operating system. It operates in a real-time environment using firmware developed with the Arduino framework, allowing direct control over the fan speed and sensors.

### 3.6.3 SMART FAN SUBSYSTEM SOFTWARE DEPENDENCIES

The subsystem’s software includes several libraries: WiFi.h for managing network connectivity, HTTP-Client.h for server communication, and ArduinoJson.h for handling JSON data exchanged between the ESP32 and the Smart Crib server. Additionally, DHT.h is used to interface with temperature and humidity sensors, while PWM.h enables PWM signal control for managing fan speed.

### 3.6.4 SMART FAN SUBSYSTEM PROGRAMMING LANGUAGES

The Smart Fan Subsystem is programmed using C/C++, leveraging the Arduino framework for precise control over the fan and sensors, as well as efficient communication with the Smart Crib server.

### 3.6.5 SMART FAN SUBSYSTEM DATA STRUCTURES

The subsystem uses JSON packets for data transmission. These packets include fields such as id, device, fanSpeed, temperature, and humidity. The ESP32 parses these JSON packets to adjust the fan speed or send sensor readings to the server, ensuring seamless communication and synchronization with the overall system.

### 3.6.6 SMART FAN SUBSYSTEM DATA PROCESSING

The Smart Fan Subsystem employs a control algorithm that adjusts fan speed based on user input or sensor readings. When operating manually, the ESP32 processes the JSON packet to set the fan speed using PWM signals. In automatic mode, the fan speed is dynamically adjusted using a proportional control algorithm based on temperature and humidity readings. The subsystem ensures that changes in fan speed are reported back to the server to maintain synchronization with the mobile application.

### 4 SERVER LAYER SUBSYSTEMS

The Cloud Server Layer encompasses two primary subsystems: the virtual machine (VM) service and the server software. The VM service facilitates the provisioning of essential computing resources, an operational environment, and internet connectivity, enabling seamless data transmission through specified network ports. This connectivity is critical as the entire system depends on robust internet communication protocols, which are effectively managed and orchestrated by the server software.

### 4.1 SERVER LAYER HARDWARE

In the Smart Crib system architecture, the server layer is hosted on an Azure Virtual Machine (VM), which provides the necessary infrastructure for handling user commands and coordinating communication between the client and IoT devices. The Azure VM is configured with Ubuntu OS, offering a stable and secure environment for hosting the Python-based HTTP server. This setup leverages the flexibility and scalability of cloud infrastructure, allowing for efficient scaling and management as the system grows.

### 4.2 SERVER LAYER OPERATING SYSTEM

The Cloud Server Layer operates on an Ubuntu-based Virtual Machine (VM), offering a stable and secure environment for running our application code. Ubuntu, a widely-used Linux distribution, provides the necessary libraries, package management, and flexibility needed for efficient software deployment. Its lightweight and efficient nature ensures minimal resource consumption while maintaining the reliability required for continuous server operations. This operating system supports the installation of essential components such as network management tools, security patches, and software dependencies, ensuring that the Smart Crib system remains responsive and secure throughout its operation.

### 4.3 SERVER LAYER SOFTWARE DEPENDENCIES

The Cloud Server Layer relies on several software dependencies to ensure smooth operation and communication between components. It utilizes Python 3 as the primary programming language, offering extensive libraries and modules to support efficient server management. The server is built on an HTTP server framework, which enables it to handle incoming and outgoing HTTP requests effectively. This setup is essential for processing commands and transmitting data between the client application and IoT devices. Additionally, various Python libraries are used to manage network connections, handle JSON data, and maintain server uptime and reliability, ensuring that the Smart Crib system remains robust and responsive.

### 4.4 REQUEST HANDLER SUBSYSTEM

The Request Handling Subsystem for the Cloud Server Layer ensures that the server remains responsive and capable of handling multiple incoming HTTP requests simultaneously. It operates by continuously listening on a designated port. When an HTTP request is received, the subsystem spawns a new thread dedicated to processing that request. This threading approach keeps the port open and available for additional requests, preventing any blocking or delays in handling new connections. Each HTTP request typically contains a JSON file with essential information, such as the origin of the request (whether it’s from the application or a connected device) and updates related to device states or relevant data. This setup allows the server to efficiently manage and process incoming data, maintaining seamless communication between the cloud infrastructure and the connected devices or application.

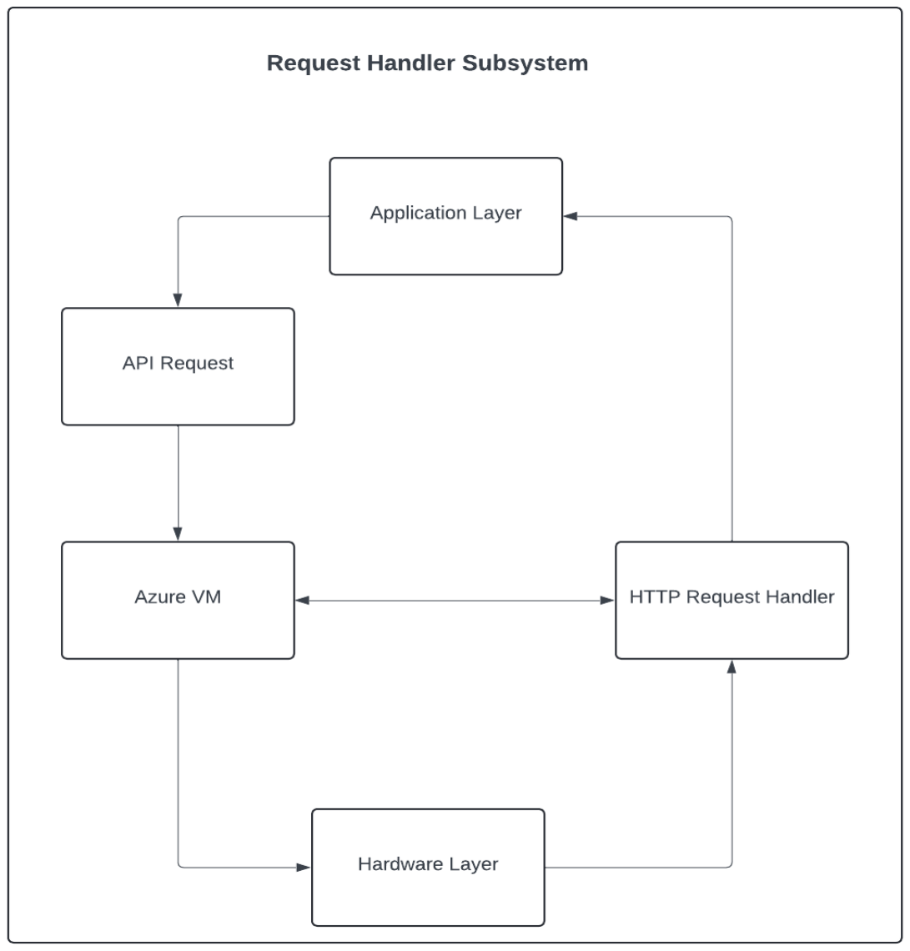
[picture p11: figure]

Figure 5: Request Handler Subsystem Diagram

### 4.4.1 REQUEST HANDLER SUBSYSTEM HARDWARE

The Request Handling Subsystem runs entirely on a virtual machine (VM) hosted on Microsoft Azure. As such, the hardware components are virtualized and managed by Azure’s infrastructure, providing computational resources, storage, and network connectivity necessary to handle HTTP requests and manage threads efficiently. The VM is configured to maintain high availability and scalability, ensuring it can handle increasing loads as the number of connected devices and requests grows.

### 4.4.2 REQUEST HANDLER SUBSYSTEM OPERATING SYSTEM

The operating system used for the Request Handling Subsystem is Ubuntu. Ubuntu, a widely-used Linux distribution, provides a stable and secure environment for running the server software. It is chosen for its compatibility with Python and its extensive support for networking services, which are essential for managing incoming HTTP requests and threading operations.

### 4.4.3 REQUEST HANDLER SUBSYSTEM SOFTWARE DEPENDENCIES

The software dependencies for the Request Handling Subsystem include Python3, which serves as the primary programming language for implementing the server and handling HTTP requests. The subsystem utilizes Python’s built-in http.server library to create an HTTP server capable of listening on the designated port and managing incoming requests. To handle multiple requests efficiently, the Python threading library is employed, allowing the server to spawn new threads for each request, thus ensuring non-blocking communication and processing. Additionally, Python’s JSON library is used for parsing incoming JSON files that contain information such as device updates and request origins, and for structuring the JSON responses sent back to the client or devices. These dependencies are crucial for maintaining the system’s functionality, efficiency, and reliability in managing real-time data processing and communication between the server, application, and connected devices.

### 4.4.4 REQUEST HANDLER SUBSYSTEM PROGRAMMING LANGUAGES

The Request Handling Subsystem is primarily implemented using Python. Python is chosen for its simplicity, flexibility, and robust support for web and network-related libraries, which are essential for handling HTTP requests and managing threading effectively.

### 4.4.5 REQUEST HANDLER SUBSYSTEM DATA STRUCTURES

The primary data structure used in the Request Handling Subsystem involves JSON objects. When a request is received, the server parses the incoming JSON data to extract information such as the source of the request (whether it is from the application or a connected device), the target device, and the relevant updates (e.g., brightness level or lock status). The JSON format is used for its lightweight nature and ease of serialization, allowing efficient transmission of structured data between the client, server, and IoT devices.

### 4.4.6 REQUEST HANDLER SUBSYSTEM DATA PROCESSING

The Request Handling Subsystem uses a multi-threading algorithm to manage incoming HTTP requests. When a request is received, a new thread is spawned, allowing the server to process the request independently while keeping the port open for other incoming connections. This prevents bottlenecks and ensures that multiple devices or applications can interact with the server simultaneously without delay. Additionally, the subsystem processes JSON data by extracting key information (such as device type and state updates) and updating the server’s state accordingly. This method ensures the system remains responsive, and the updates are processed in real-time, providing users with seamless control over their connected devices.

### 5 DEVICE LAYER SUBSYSTEMS

Our device layer subsystem consists of three main components: the microcontroller, the hardware components, and the supporting software. The microcontroller plays a critical role in enabling independent device functionality, operating autonomously from other systems. It interfaces with the hardware components, which allow us to interact with the physical environment. The software leverages these components to execute the specific tasks required by the system.

### 5.1 DEVICE LAYER HARDWARE

The Device Layer hardware comprises two primary microcontrollers: the ESP32 and the Raspberry Pi Pico. The ESP32 is responsible for controlling the smart light and door lock devices, leveraging its built-in Wi-Fi capabilities for seamless communication with the cloud server. The Raspberry Pi Pico is used for the smart fan subsystem, chosen for its efficient processing and GPIO capabilities. These microcontrollers interface with various sensors and actuators to manage device states and respond to server commands. Each microcontroller is equipped with hardware components like relays, sensors, and motors that enable physical interaction with the environment.

### 5.2 DEVICE LAYER OPERATING SYSTEM

The Device Layer does not use a traditional operating system, as both the ESP32 and Raspberry Pi Pico operate in a bare-metal configuration. This lightweight setup is ideal for IoT applications, enabling direct control over hardware resources without the overhead of an operating system.

### 5.3 DEVICE LAYER SOFTWARE DEPENDENCIES

The Device Layer software relies on several libraries tailored to the microcontrollers. For the ESP32, the Arduino framework provides a development environment with libraries for managing Wi-Fi communication and interfacing with sensors and actuators. The Raspberry Pi Pico uses the MicroPython environment, allowing for easy coding and deployment on the device. Key libraries include networking libraries for communication protocols and sensor libraries for reading and transmitting device status.

### 5.4 SMART LIGHT SUBSYSTEM

The Smart Light Subsystem is designed to provide dynamic lighting control within the Smart Crib system, integrating hardware components such as an LED light module and a motion sensor with an ESP32 microcontroller. The subsystem’s primary function is to adjust the brightness and color of the LED light based on user input received from the server, as well as to detect motion and trigger light changes independently. The ESP32 microcontroller acts as the central controller, communicating with the server to receive updates, and directly interfacing with the LED module and motion sensor for real-time adjustments.

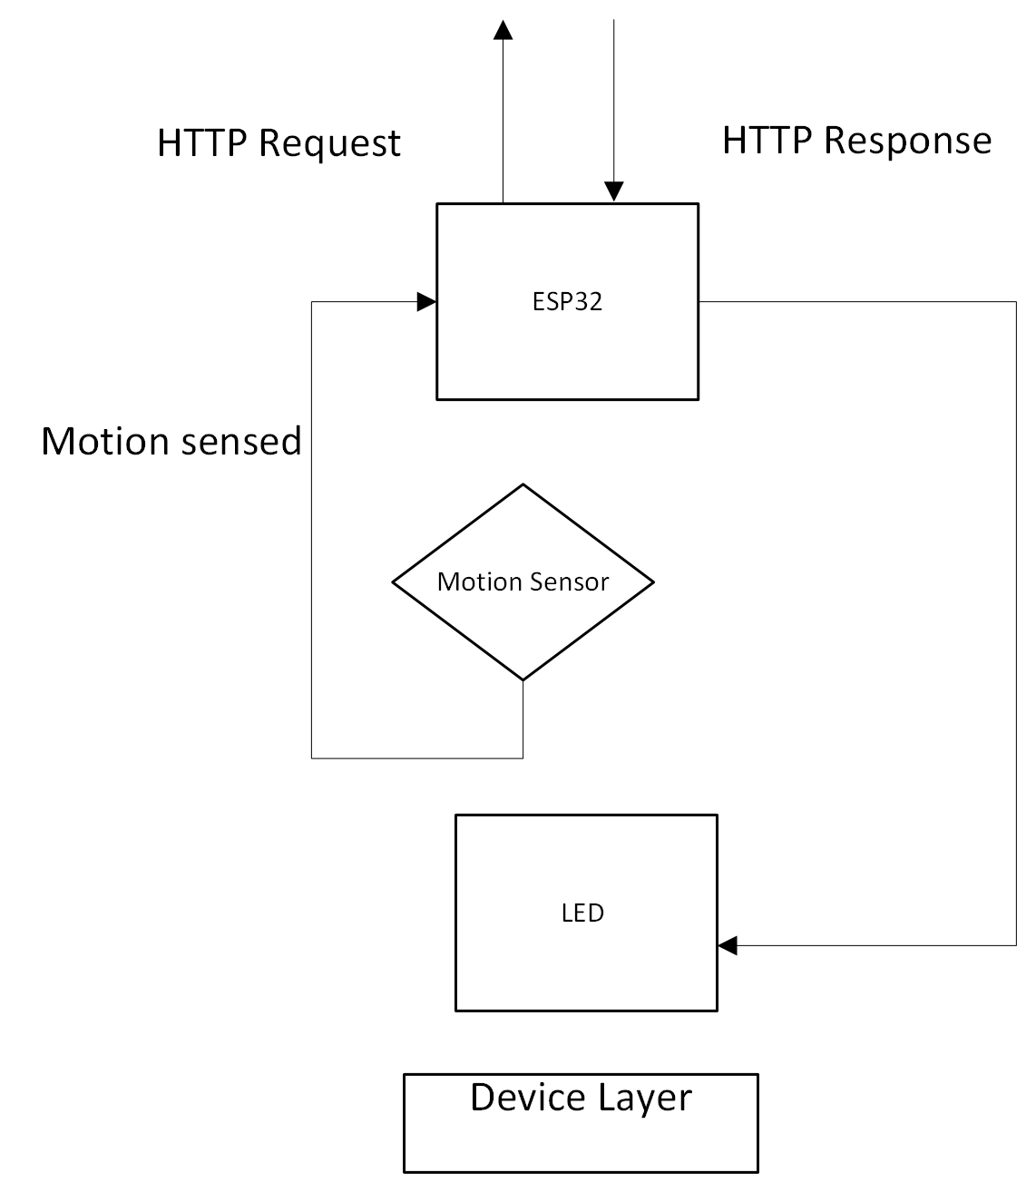
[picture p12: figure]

Figure 6: Smart Light Device Subsystem Diagram

### 5.4.1 SUBSYSTEM HARDWARE

The hardware for the Smart Light Subsystem includes an ESP32 microcontroller powered by a 5V source, an LED light module capable of adjustable brightness and color, and a motion sensor module for detecting movement. The ESP32 manages the communication and functionality of these components, using its GPIO pins to control the LED module via a signal wire and receive inputs from the motion sensor. The

LED module is equipped with integrated circuitry to simplify brightness and color adjustments based on signals sent by the ESP32, while the motion sensor provides detection signals that trigger actions.

### 5.4.2 SUBSYSTEM OPERATING SYSTEM

The Smart Light Subsystem does not rely on a traditional operating system. Instead, it operates on a bare-metal configuration using the ESP32 microcontroller, which executes instructions directly without the overhead of a complex OS. This lightweight setup ensures minimal latency and quick response times for controlling the lighting system and processing motion sensor data.

### 5.4.3 SUBSYSTEM SOFTWARE DEPENDENCIES

The software dependencies for the Smart Light Subsystem include the Arduino IDE, which provides a development environment for programming the ESP32 microcontroller. Additionally, several libraries are used: the Adafruit LED Light module library for controlling the LED brightness and color, the ESP32 board package for Arduino IDE compatibility, and the Arduino JSON library for parsing and structuring JSON data. The HTTP client library is also utilized to manage server communications, enabling the ESP32 to send and receive JSON-formatted data through HTTP requests.

### 5.4.4 SUBSYSTEM PROGRAMMING LANGUAGES

The Smart Light Subsystem is programmed primarily using the C language through the Arduino IDE. This programming language allows for low-level access to the microcontroller’s hardware features, providing precise control over the LED light module and motion sensor.

### 5.4.5 SUBSYSTEM DATA STRUCTURES

The Smart Light Subsystem uses JSON objects as the primary data structure for communication with the server. Each request sent to the server contains a JSON object with information such as device identification, current hardware state, and user-specified updates (e.g., brightness levels). The JSON format allows for efficient data serialization and easy parsing by both the server and the microcontroller, ensuring effective communication and control over the smart lighting system.

### 5.4.6 SUBSYSTEM DATA PROCESSING

The Smart Light Subsystem processes data using two main strategies. First, it sends HTTP requests to the server every second, each containing a JSON file identifying the device and its state. The server responds with updated lighting parameters, which the ESP32 then compares with the current state to determine if an adjustment is necessary. The subsystem also features independent processing: when motion is detected by the sensor, the microcontroller triggers the LED light for a preset duration. This local control does not depend on server interaction, ensuring that basic lighting functions remain operational even if the network connection is disrupted.

### 5.5 SMART LOCK DEVICE SUBSYSTEM

The Smart Lock Device Subsystem is a hardware-based solution designed to manage the physical locking and unlocking of the Smart Crib door. At its core, the subsystem utilizes an ESP32 microcontroller, which serves as the control unit for the locking mechanism. The microcontroller coordinates with several components: a linear actuator for the physical lock movement, relay switches to manage the actuator’s activation, a 12V rechargeable battery for power, and 5V step-down modules to regulate power to smaller components. Additionally, a keypad and an unlock button provide user input options directly on the device. The software is programmed in C using the Arduino IDE, leveraging its compatibility with various libraries, such as those for the keypad module, which facilitates easier development and integration. The subsystem employs multithreading to handle multiple tasks simultaneously, including processing server updates that provide app-based control and monitoring keypad inputs for user PIN verification. The microcontroller sends HTTP requests to the server to sync the lock’s state, ensuring real-time updates based on user actions through the mobile app. If the correct PIN is entered via the keypad, the device initiates an unlock sequence. Key software dependencies include the ESP32 board support package, the Arduino JSON library for parsing data, the HTTP client for server communication, and the keypad library. This architecture allows for seamless integration of hardware and software components to provide both app-based and physical control of the door lock.

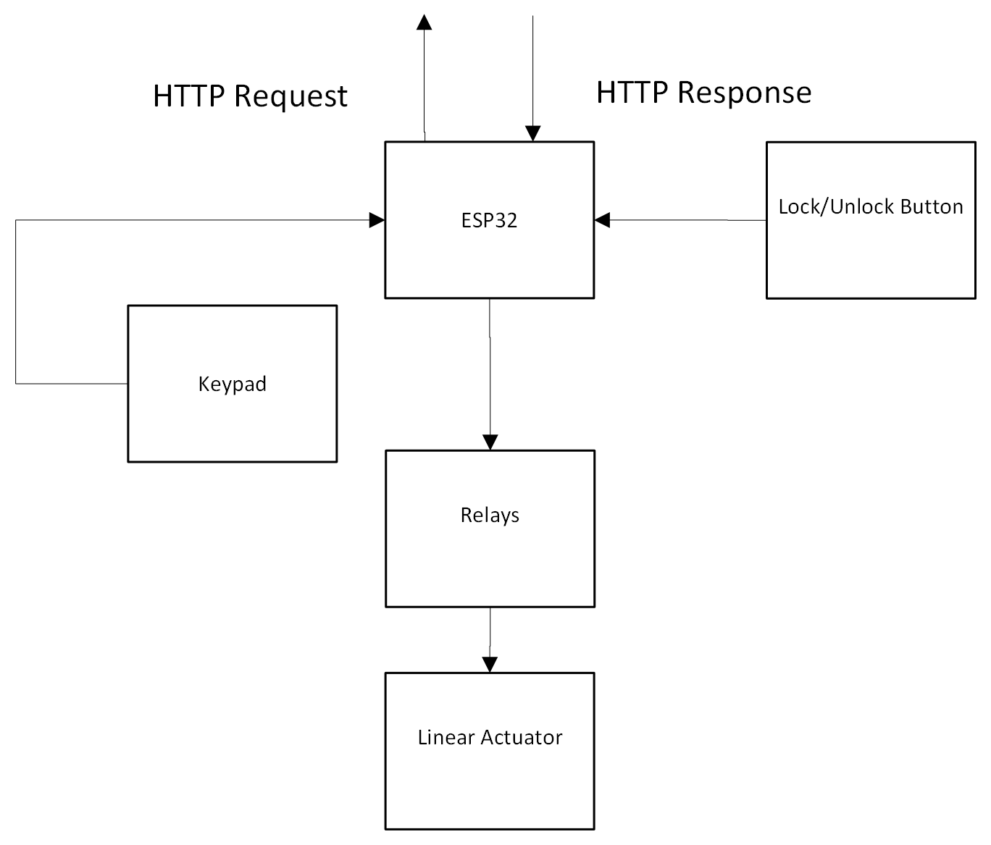
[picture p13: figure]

Figure 7: Smart Lock Device Subsystem Diagram

### 5.5.1 SMART LOCK SUBSYSTEM HARDWARE

The hardware includes an ESP32 microcontroller, a linear actuator for the locking mechanism, relay switches for controlling the actuator, a 12V rechargeable battery, 5V step-down modules for power regulation, a keypad for external input, and an unlock button for internal control.

### 5.5.2 SMART LOCK SUBSYSTEM OPERATING SYSTEM

The ESP32 microcontroller operates on its integrated firmware, compatible with the Arduino platform.

### 5.5.3 SMART LOCK SUBSYSTEM SOFTWARE DEPENDENCIES

Dependencies include the ESP32 board package, the Arduino JSON library for data processing, an HTTP client for server communication, and the keypad library for reading user inputs.

### 5.5.4 SMART LOCK SUBSYSTEM PROGRAMMING LANGUAGES

The programming language used for the subsystem is C, leveraging the Arduino IDE for development.

### 5.5.5 SMART LOCK SUBSYSTEM DATA STRUCTURES

The data transmitted between the ESP32 and the server is structured as JSON packets containing device IDs, state updates, and command confirmations. The packets are parsed using the Arduino JSON library.

### 5.5.6 SMART LOCK SUBSYSTEM DATA PROCESSING

The subsystem employs algorithms for multithreading to manage simultaneous tasks like monitoring keypad inputs and processing server updates. It also implements input validation algorithms for secure PIN verification and state synchronization routines to align physical lock states with server commands.

### 5.6 SMART FAN SUBSYSTEM

The Smart Fan Subsystem is a hardware-based solution designed to control the operation and speed of a fan within the Smart Crib environment. At its core, the subsystem utilizes a Raspberry Pi Pico microcontroller, which serves as the control unit for the fan’s operation. The microcontroller coordinates with several components: a motor driver to control the fan motor speed, temperature sensors to monitor the environment, and a relay switch to manage the fan’s power state. The fan’s speed is adjusted based on temperature readings, ensuring that the environment is maintained at optimal comfort levels. The software is programmed in C using the Arduino IDE, taking advantage of its compatibility with various libraries, such as those for temperature sensing and motor control, which facilitate efficient development and integration. The subsystem employs multithreading to handle concurrent tasks, such as reading temperature values, adjusting fan speed, and communicating with the server for remote control. The microcontroller sends periodic updates to the server, reporting the fan’s current state and temperature readings, and receives commands from the app for manual speed adjustments. Key software dependencies include the Raspberry Pi Pico board package, temperature sensor libraries for reading environmental data, and motor control libraries for managing fan speed. This architecture allows for an integrated approach, combining sensor data and remote commands to provide both automatic and manual control of the fan.

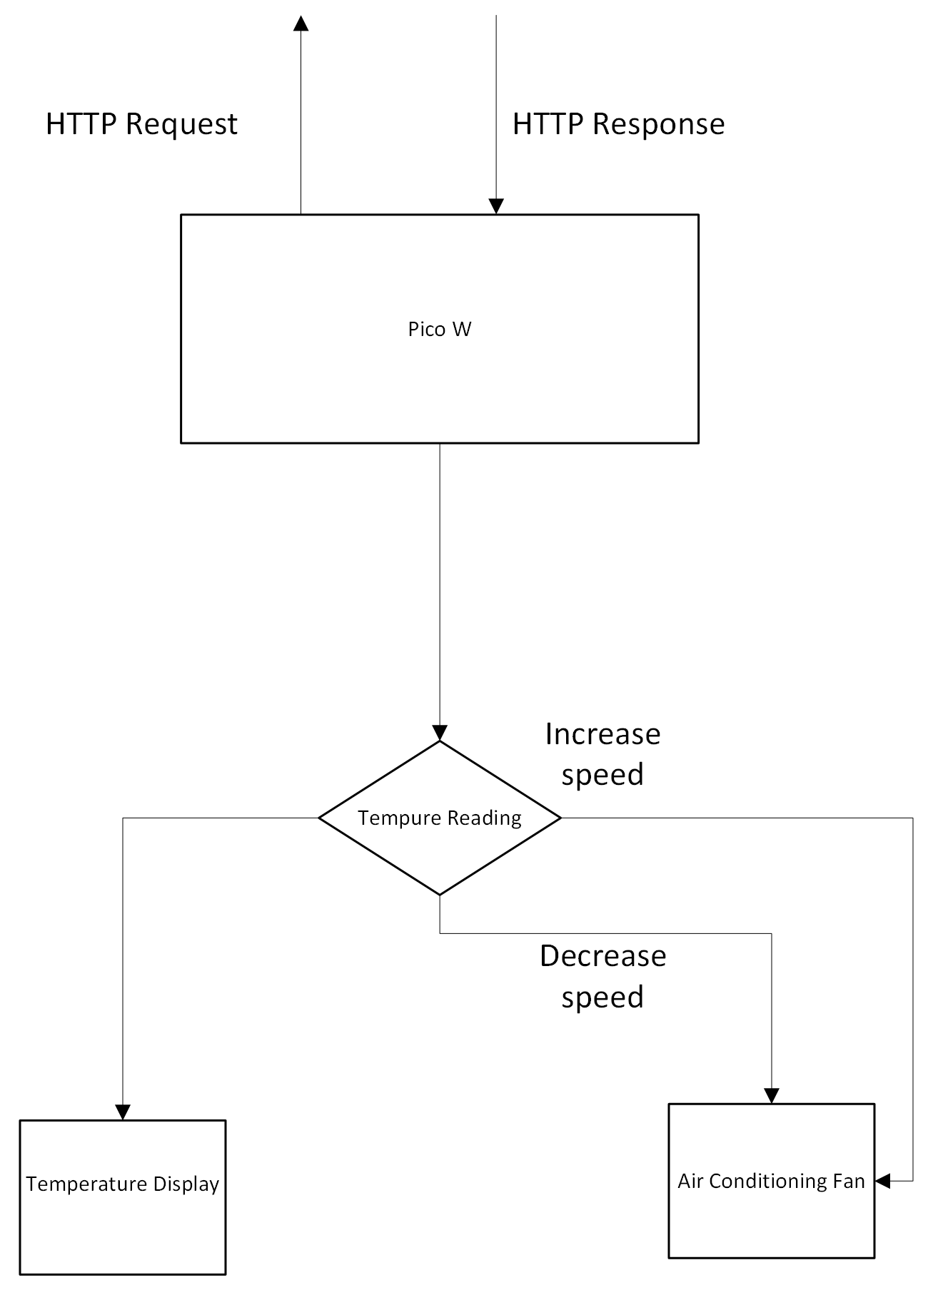
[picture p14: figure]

Figure 8: Smart Fan Device Subsystem Diagram

### 5.6.1 SMART FAN SUBSYSTEM HARDWARE

The hardware includes a Raspberry Pi Pico microcontroller, a motor driver for controlling fan speed, temperature sensors for monitoring environmental conditions, and a relay switch for managing the fan’s power state.

### 5.6.2 SMART FAN SUBSYSTEM OPERATING SYSTEM

The Raspberry Pi Pico operates using its integrated firmware, compatible with the Arduino platform for development.

### 5.6.3 SMART FAN SUBSYSTEM SOFTWARE DEPENDENCIES

Dependencies include the Raspberry Pi Pico board package, libraries for temperature sensing, motor control libraries, and an HTTP client library for server communication.

### 5.6.4 SMART FAN SUBSYSTEM PROGRAMMING LANGUAGES

The programming language used for the subsystem is C, leveraging the Arduino IDE for development.

### 5.6.5 SMART FAN SUBSYSTEM DATA STRUCTURES

Data transmitted between the Raspberry Pi Pico and the server is structured as JSON packets containing temperature readings, fan speed, and device status. The JSON library is used for assembling and parsing these packets.

### 5.6.6 SMART FAN SUBSYSTEM DATA PROCESSING

The subsystem uses algorithms for multithreading to manage simultaneous tasks, such as monitoring temperature and controlling fan speed. It also implements a PID (Proportional-Integral-Derivative) control algorithm for precise fan speed adjustments based on temperature variations, ensuring efficient and responsive environmental management.

### 6 APPENDIX A

APPENDIX A: SMART LIGHT CIRCUIT SCHEMATIC

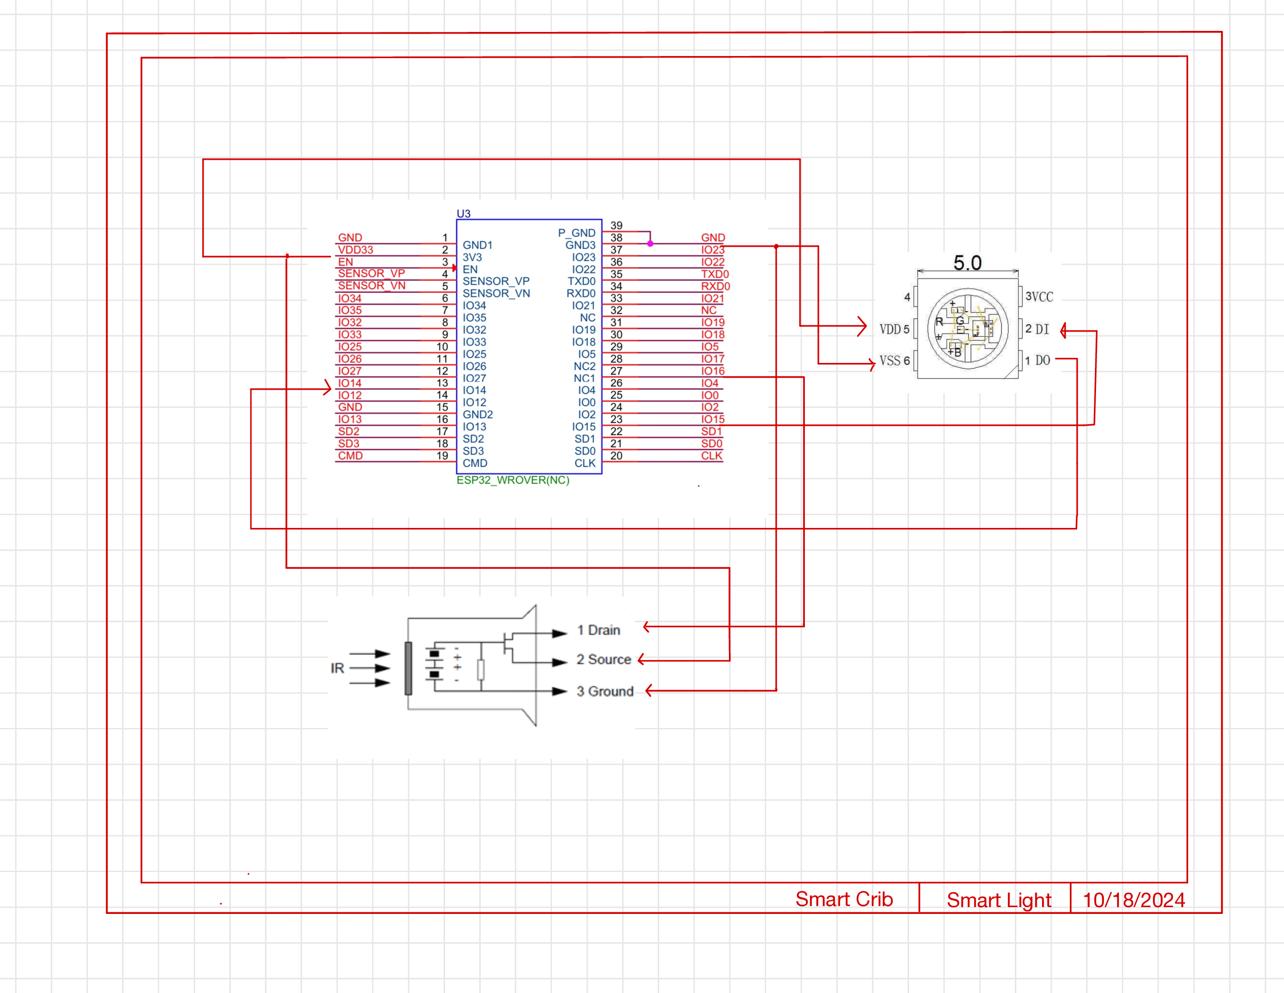
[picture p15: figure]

Figure 9: Circuit Schematic for the Smart Light Subsystem

APPENDIX B: SMART LOCK CIRCUIT SCHEMATIC

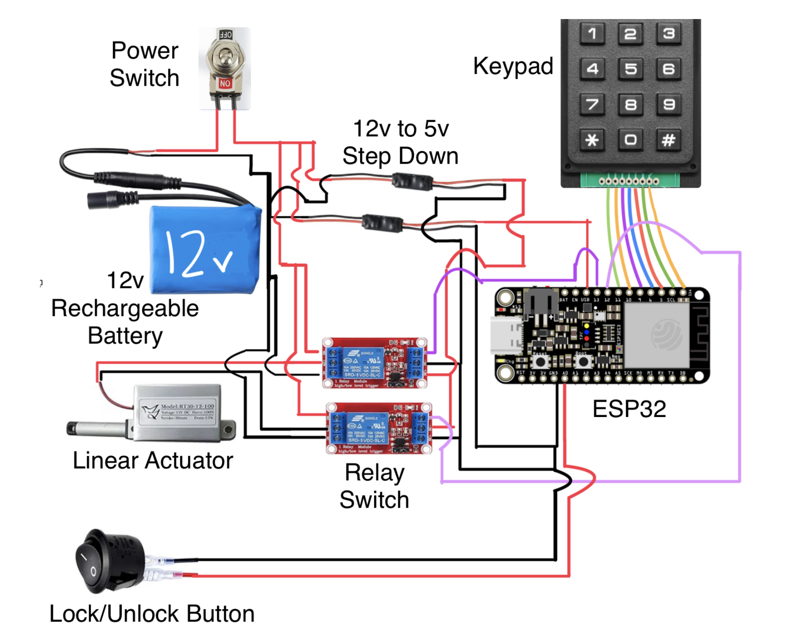
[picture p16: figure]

Figure 10: Circuit Schematic for the Smart Lock Subsystem

APPENDIX C: SMART FAN SUBSYSTEM CIRCUIT SCHEMATIC

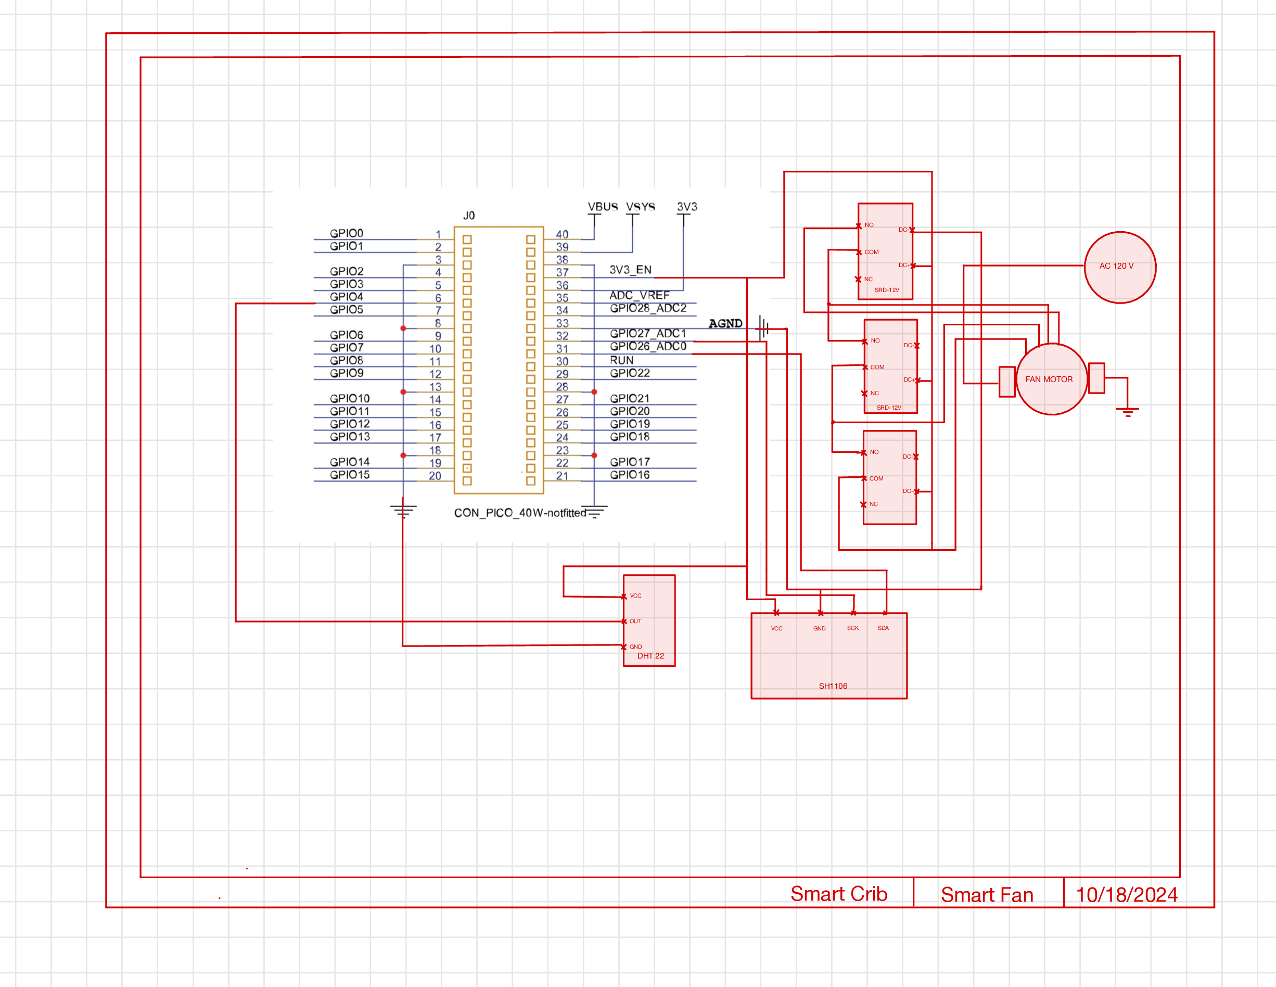
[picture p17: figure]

Figure 11: Circuit Schematic for the Smart Fan Subsystem

REFERENCES

[1] Arshdeep Bahga and Vijay Madisetti. Internet of Things: A Hands-On Approach. VPT, Atlanta, GA, 1st edition, 2014.
[2] Francesco De Pellegrini Daniele Miorandi, Sabrina Sicari and Imrich Chlamtac. Internet of Things: Vision, Applications and Research Challenges. Wiley, Hoboken, NJ, 1st edition, 2014.
[3] Samuel Greengard. The Internet of Things. MIT Press, Cambridge, MA, 1st edition, 2015.
[4] John Lee and Sanjay S. Kumar. The Internet of Things in the Industrial Sector: Applications and Impacts. Wiley, Hoboken, NJ, 1st edition, 2018.
[5] David L. Brock Sanjay E. Sarma and John R. Williams. The Internet of Things: Roadmap to a Connected World. Taylor & Francis, Boca Raton, FL, 1st edition, 2016.
[1] [3] [4] [2] [5]

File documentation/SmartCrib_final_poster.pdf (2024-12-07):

Dang, D., Del Rio, L., Martinez, Z., Pujar, P.

# Smart Crib IoT

- Seamless User Experience: Create a unified platform for controlling multiple smart devices remotely, reducing the complexity of managing individual systems.
- Scalability and Integration: Design a modular system capable of integrating additional devices in the future without significant redesign.
- Reliability: Ensure robust and responsive communication between the cloud server and hardware devices to maintain consistent functionality.

Figure 5: Circuit Schematic for Smart Lock

## Conclusions and Future Work

The Smart Crib project successfully meets the client’s goals by delivering an integrated, user-friendly system for managing smart lights, a smart door lock, and a smart fan. The mobile application provides seamless control, while the Azure Virtual Machine ensures real-time responsiveness, aligning with technical and performance specifications. Valuable lessons included the importance of robust cloud-device communication and balancing hardware constraints with scalability. Future plans involve expanding device support, integrating predictive automation, and enhancing security, with gratitude extended to the client, sponsors, and open-source contributors for their support.

1. Johnson, M. T., and Zhang, H., “Optimizing IoT Device Communication for Smart Home Applications,” IEEE Transactions on Internet of Things, 2021, Vol 8, pp 1457-1468.
2. Gupta, R., and Singh, A., “Energy-Efficient Lighting Solutions for Smart Homes,” International Journal of Smart Systems and Technologies, 2020, Vol 12, pp 89-103.
3. Brown, C., and Miller, J., “Enhancing Security in Smart Locks: A Comprehensive Review,” Journal of Computer Science and Information Security, 2019, Vol 15, pp 45-56.
4. Smith, L., and Davis, R., “Cloud-Based Control Systems for IoT Applications,” ASME Journal of Computing and Information Science in Engineering, 2022, Vol 22, pp 112-120.
5. Patel, V., and Kumar, N., “Integration of ESP32 Microcontrollers in IoT Systems,” IEEE Internet of Things Journal, 2021, Vol 7, pp 3342-3350.

## References

Background | Demos

## Design Requirements

The Smart Crib project integrates hardware and software components to provide users with a seamless and efficient smart home management solution. The system features smart lights, a smart door lock, and a smart fan, all of which can be controlled remotely through a user-friendly mobile application. The application serves as the central interface, allowing users to adjust light brightness, lock and unlock doors via a keypad or app controls, and set fan speeds. Communication between the app and devices is facilitated through an Azure Virtual Machine (VM) server, which processes HTTP control commands and maintains device statuses in real time.

The hardware layer includes an ESP32 microcontroller for the smart door lock & light and a Raspberry Pi Pico for the smart fan, enabling autonomous operations and network communication. The smart door lock features a keypad for local passcode input, providing an additional layer of security. The smart fan allows speed adjustments for customized comfort, while the smart lights support dynamic brightness levels for personalized lighting. By leveraging cloud-based infrastructure and efficient task management on microcontrollers, the Smart Crib project ensures reliable, responsive, and secure smart home control, blending convenience with cutting-edge IoT technology.

December 2024

## Senior Design

Figure 5: System Architecture

Figure 3: Smart Light OFF | Figure 4: Smart Light ON

Figure 6: Smart Fan PCB

## Printed Circuit Board

Figure 1: Smart Fan | Figure 2: Smart Door Lock

## System Design

Figure 7: Old Smart Fan Model

## Old Smart Fan Model

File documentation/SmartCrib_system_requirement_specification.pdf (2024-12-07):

DEPARTMENT OF COMPUTER SCIENCE & ENGINEERING THE

UNIVERSITY OF TEXAS AT ARLINGTON

# SYSTEM REQUIREMENTS SPECIFICATION

## CSE 4316: SENIOR DESIGN I Summer 2024


## SMARTCRIB

DON DANG

ZAIT MARTINEZ

LUIS DEL RIO CARRILLO
PRANAV UMAKANT PUJAR
Smart Crib Summer 2024 | Page 1 of 27

REVISION HISTORY

Revision | Date | Author(s) | Description
0.1 | 07.14.2024 | Don Dang, Luis Del Rio Carrillo, Zait Martinez, Pranav Pujar | document creation
1.0 | 07.15.2024 | Don Dang | Complete Product Concept
1.1 | 07.15.2024 | Don Dang | Complete Product Description
1.2 | 07.15.2024 | Don Dang | Complete Customer Requirements
2.0 | 07.16.2024 | Zait Martinez | Complete Package Requirements
3.1 | 07.17.2024 | Don Dang | Completed Performance Requirements
3.2 | 07.18.2024 | Luis Del Rio | Completed Safety Requirements
4.0 | 07.18.2024 | Don Dang & Zait Martinez | Completed Maintenance & Support Requirements
4.1 | 07.18.2024 | Pranav Pujar & Don Dang | Completed Other Requirements
4.2 | 07.19.2024 | Don Dang | Completed Future Items
5.0 | 07.21.2024 | Don Dang | Final document edit

CONTENTS

1 Product Concept | 6
1.1 Purpose and Use | | 6
1.2 Intended Audience | | 6
2 Product Description | 9
2.1 Features & Functions | | 9
2.2 External Inputs & Outputs | | 9
2.3 Product Interfaces | | 9
3 Customer Requirements | 8
3.1 Requirement Name | | 8
3.1.1 Description | | 8
3.1.2 Source | | 8
3.1.3 Constraints | | 8
3.1.4 Standards | | 8
3.1.5 Priority | | 8
3.2 Requirement Name | | 8
3.2.1 Description | | 8
3.2.2 Source | | 9
3.2.3 Constraints | | 9
3.2.4 Standards | | 9
3.2.5 Priority | | 9
4 Packaging Requirements | 18
4.1 Hardware/Electronics | | 18
4.1.1 Description | | 18
4.1.2 Source | | 18
4.1.3 Constraints | | 18
4.1.4 Standards | | 18
4.1.5 Priority | | 8
5 Performance Requirements | 20
5.1 Real-Time Processing | | 20
5.1.1 Description | | 20
5.1.2 Source | | 20
5.1.3 Constraints | | 20
5.1.4 Standards | | 20
5.1.5 Priority | | 20
6 Safety Requirements | 12
6.1 Laboratory equipment lockout/tagout (LOTO) procedures | | 12
6.1.1 Description | | 12
6.1.2 Source | | 12
6.1.3 Constraints | | 12
6.1.4 Standards | | 12
6.1.5 Priority | | 12

7 Maintenance & Support Requirements | 14
8 Other Requirements | 15
9 Future Items | 16

LIST OF FIGURES
1.SmartCrib Conceptual Drawing 2.Network Communication
3.Conceptual Diagram
- Direct Control To Device Through Local Network Connection For Prototyping UI Application and Features.

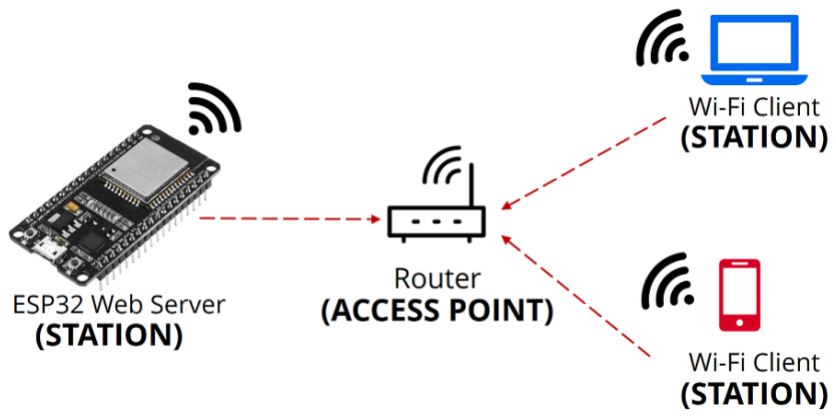
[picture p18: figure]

-Centralized Server & Database Connecting All Localized Devices for Easier Device Expandability, with Internet Access Mobile Application allowing for Multiple Users

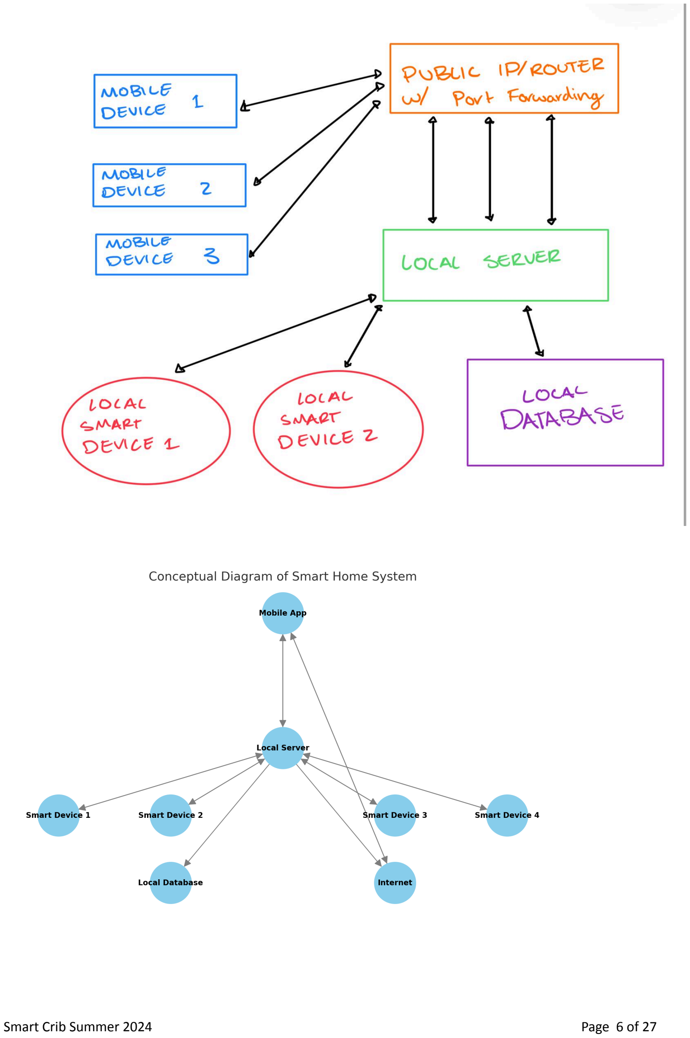
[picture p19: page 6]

### 1 PRODUCT CONCEPT

Our Product is a Smart Home system which will be built on multiple systems working together. This includes the user's Mobile application, a home wifi network, smart devices that connect to the local wifi network, and a local server along a local database. The Goal is to have a central server that is local, this will access both the database which contains data of all devices around the house, and the devices themselves. Through this local server the devices will be able to communicate with one another having access to the data on other devices will allow each and every device to adapt and change accordingly to make the home automation system a smooth operation where all devices are aware of any data that could be important to them. The local server will have internet access allowing Users to use a Mobile App to access all important data from the database. The user will then be able to adjust individual devices as desired. The system will allow for multiple users and multiple devices to be added. The design will make integration of new devices and features to further expand your home automation experience.

### 1.1 PURPOSE AND USE

This is where you describe in a brief, yet clear and concise, manner what your product should do and how you expect it should be used.
The purpose of our System is to have a centralized/localized home automation network where all devices can communicate with one another shared data and even ask other devices to do things without the need for an internet connection (local wifi connection still necessary). Things will be automated and control of this system will be accessible through the local network or Via internet connection. However the goal is to rely as little as possible on the user for any tasks. It is meant to be a smooth coherent system to make the users day to day life easier, not to give the user the responsibility of controlling and orchestrating all the devices to work together which is what we see in today's smart home applications.

### 1.2 INTENDED AUDIENCE

The intended Audience is any homeowner or person living within the household. It is intended to be easy to use through a Mobile Phone app. The goal is to have a centralized Application where everything is located and controlled. Initial build will be general use but with the use of open source components it will allow others who are more tech savvy to possibly add their own custom devices.

Figure 1: Smart Light Device

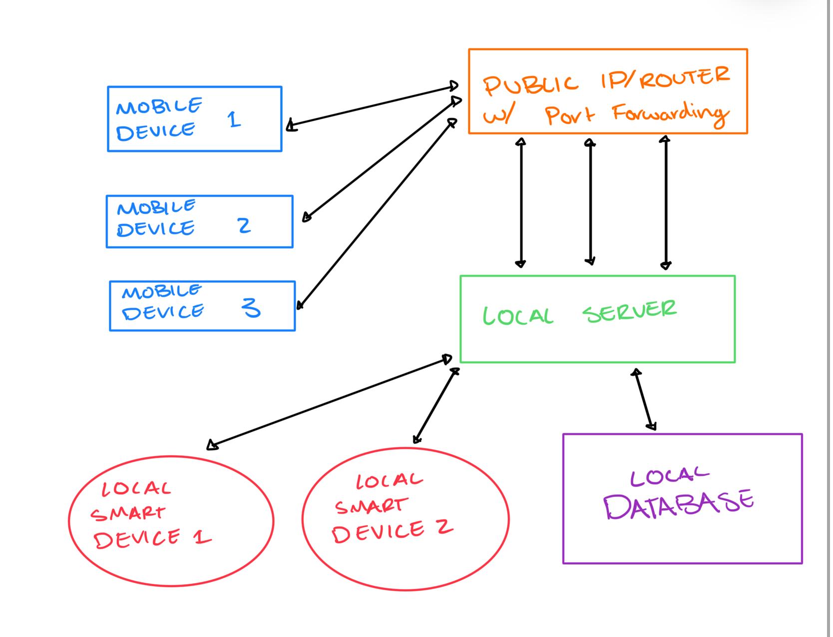
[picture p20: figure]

### 2 PRODUCT DESCRIPTION

The Smart Light Automation System is an innovative IoT solution designed to seamlessly integrate and control smart light bulbs in residential and commercial settings. This system allows users to automate lighting based on schedules, motion detection, and ambient light levels, providing optimal energy efficiency and convenience.

### 2.1 FEATURES & FUNCTIONS

Our Smart Home system is designed to create a seamless and automated home environment through the integration of various smart devices and a centralized local server.

Features:

- Centralized Local Server: Acts as the brain of the system, managing communication between devices and storing data locally.
- Mobile Application: Provides a user-friendly interface for users to monitor and control their smart home devices.
- Smart Devices Integration: Supports various smart devices (e.g., lights, thermostats, security cameras) that connect to the local Wi-Fi network and communicate with the central server.
- Local Database: Stores data from all connected devices, allowing the system to adapt and respond based on real-time information.
- Internet Access: Enables remote access and control of the system through the mobile application.

Functions:

- Device Communication: Allows devices to share data and execute commands based on information from other devices.
- User Control: Users can adjust device settings and automate routines via the mobile app.
- Automation: Automates tasks based on user preferences and device interactions, minimizing the need for manual intervention.

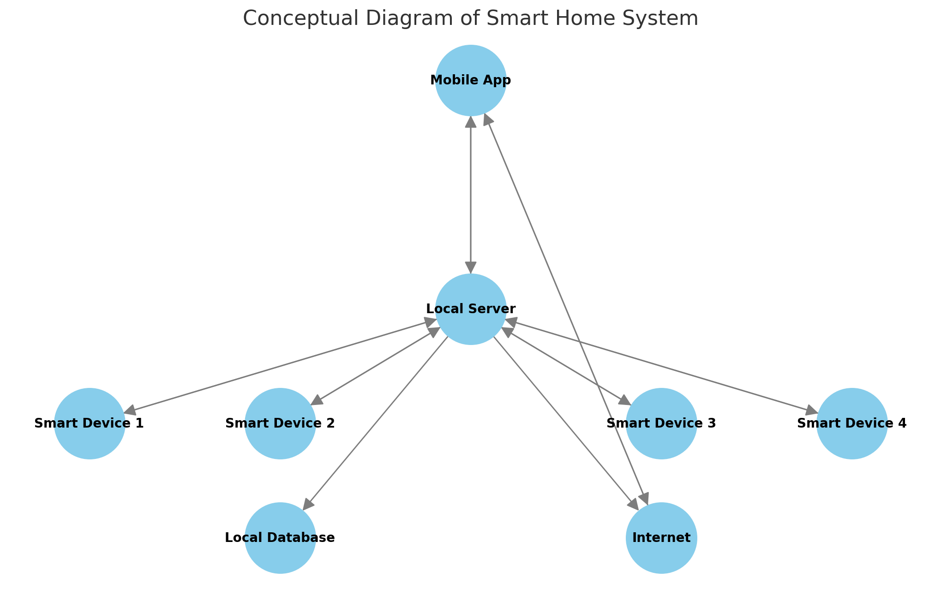
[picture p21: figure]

Diagram Explanation:

- Central Server: Local server managing data flow and device communication.
- Smart Devices: Includes lights, thermostats, cameras, etc. (the smart home component devices) connected via the local Wi-Fi network.
- Mobile Application: Interface for user interaction accessible locally or remotely.
- External Elements: Internet access for remote control, potential integration with third-party services.

### 2.2 External Input & Outputs

Name | Description | Use
User Commands | Instructions from the mobile app | Adjust device settings, trigger actions
Device Status | Real-time data from smart devices | Monitor device status, automate actions
Environmental Data | Sensor data (temperature, motion, etc.) | Trigger automated responses
Notifications | Alerts and updat es to the mobile app | Inform users of important events
Remote Commands | Instructions sent via the internet | Enable remote control
Device Data Logs | Historical data stored in the local database | Analyze trends, improve automation

### 2.3 PRODUCT INTERFACE

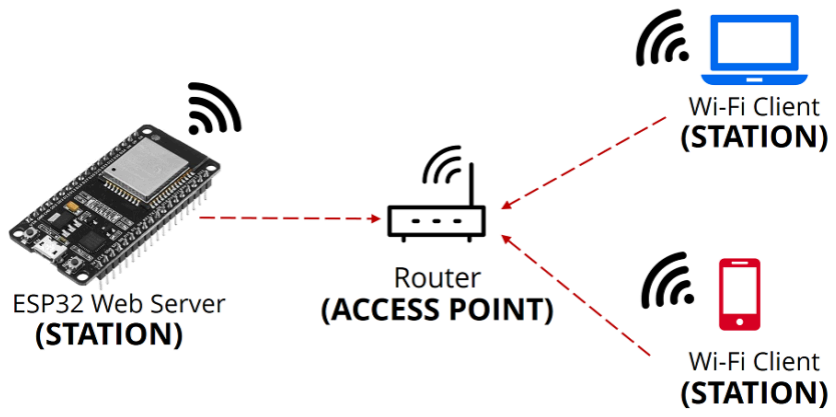
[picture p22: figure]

The operational interfaces provide a user-friendly experience for end-users, administrators, and maintainers.

End-User Interface:

1. Mobile Application Dashboard: Displays an overview of all connected devices, current status, and controls for each device.
2. Control Panels: Interface for adjusting device settings, creating automation routines, and viewing notifications.
3. Server Management Console: Provides tools for managing the local server, monitoring system health, and troubleshooting.Maintainer Interface:
1. Maintenance Dashboard: Interface for maintaining and updating the system, including device firmware updates and network management.
2. These interfaces are designed to provide a seamless and intuitive user experience, ensuring that users can easily manage and control their smart home environment.

### 3 CUSTOMER REQUIREMENTS

Customers require a Smart Light Automation System that offers seamless integration with existing smart home ecosystems, providing intuitive and user-friendly control via mobile apps or voice commands. They seek energy-efficient solutions with automated scheduling, motion detection, and ambient light sensing to enhance convenience and reduce electricity consumption. Additionally, robust security, regular software updates, and reliable customer support are essential to ensure a hassle-free and secure user experience.

### 3.1 REQUIREMENT NAME

Centralized Local Server

### 3.1.1 DESCRIPTION

The central server will act as the primary hub for all device communications and data management within the Smart Home system. It will store data locally, ensuring that devices can operate independently of internet connectivity. The server will facilitate device-to-device communication, enabling seamless integration and automation of tasks.

- The server will be a dedicated hardware unit with sufficient processing power and storage capacity to handle multiple devices.

- It will have an intuitive user interface for system administrators to manage and configure the network.
- The server will be able to interface with the local database and mobile application, providing real-time updates and control options to the user.

### 3.1.2 SOURCE

Customer feedback and requirements were gathered through brainstorming and collecting feedback on ideas from home owners and families, primarily from homeowners interested in home automation.

### 3.1.3 CONSTRAINTS

Economic: The cost of the server hardware should be kept within budget constraints to ensure affordability.
Environmental: The server should have a low power consumption design to minimize the environmental footprint.
Social: The system should be user-friendly and accessible to all household members.
Political: Compliance with local and international data privacy regulations is mandatory.
Health & Safety: The server should meet safety standards to prevent overheating and electrical hazards.
Manufacturability: The server design should allow for scalable production.
Sustainability: Use of recyclable materials in the server's construction is encouraged.

### 3.1.4 STANDARDS

- IEEE 802.11: For Wi-Fi communication.
- IEEE 802.3: For Ethernet connections.
- NIST SP 800-53: For data security and privacy controls.
- UL 60950-1: Safety standards for information technology equipment.

### 3.1.5 PRIORITY

Critical (must have or product is a failure)

### 3.2 REQUIREMENT NAME

Mobile Application Interface

### 3.2.1 DESCRIPTION

The mobile application will serve as the primary user interface for interacting with the Smart Home system. It will provide users with real-time control and monitoring capabilities over their smart devices. The app will be compatible with both iOS and Android platforms.

- The app will feature a dashboard displaying the status of all connected devices.
- Users will be able to configure and control individual devices, set up automation routines, and receive notifications.
- The interface will be intuitive and user-friendly, designed with accessibility in mind.

### 3.2.2 SOURCE

Customer feedback and requirements were gathered through brainstorming and collecting feedback on ideas from home owners and families, primarily from homeowners interested in home automation.

### 3.2.3 CONSTRAINTS

Economic: Development and maintenance costs must be managed to stay within the project budget. Social: The app should be accessible to users with varying levels of technical proficiency.
Health & Safety: The app must be designed to prevent unauthorized access and ensure data security. Manufacturability: The app should be developed using cross-platform frameworks to streamline updates and maintenance.

### 3.2.4 STANDARDS

ISO 9241-210: Ergonomics of human-system interaction.
WCAG 2.1: Web Content Accessibility Guidelines for ensuring app accessibility. ISO/IEC 27001: Information security management standards.

### 3.2.5 PRIORITY

High (very important to customer acceptance, desirability)

### 4 PACKAGING REQUIREMENTS

The packaging requirements for Smart Crib focus on ensuring the hardware and software components are protected, reliable, and user-friendly following constraints and standards.

### 4.1 Hardware/Electronics

### 4.1.1 DESCRIPTION

The physical components for Smart Crib will include sensors, microcontrollers, communication modules, power supplies, and enclosures. These components must be packaged in a way that ensures durability, ease of installation, and protection against environmental factors e.g moisture, temperature, pressure, vibration, and chemicals

### 4.1.2 SOURCE

Components will be sourced from reputable suppliers known for high-quality electronics and IoT devices. Preferred suppliers include Mouser Electronics, Adafruit, Digi-Key, Vilros, Cana Kit, Micro Center

### 4.1.3 CONSTRAINTS

- Compliance: All components must comply with relevant safety and electromagnetic compatibility (EMC) standards
- Environmental Protection: The packaging must protect the hardware from dust, moisture, and potential physical damage.
- Size and Weight: The packaging should be compact and lightweight to facilitate easy deployment and handling.
- Heat Dissipation: Adequate ventilation or heat sinks should be included to manage heat generated by the electronics

### 4.1.4 STANDARDS

- IP (Ingress Protection) Ratings: Ensuring that the enclosures meet IP65 standards for dust and water resistance.
- RoHS (Restriction of Hazardoues Substances): Compliance with RoHS to limit the use of hazardous materials in the electronics
- UL (Underwriters Laboratories) Certification: Ensuring that components are UL certified for safety.

### 4.1.5 PRIORITY

High

## 4.2 Software

### 4.2.1 Description

The software component of Smart Crib includes the firmware for the devices, the backend server software, and the user interface. It must be developed and packaged to ensure security, scalability, and ease of deployment.

### 4.2.2 Source

Software tools and libraries will be sourced from trusted open-source communities and reputable software vendors. Primary sources include GitHub for open-source software and AWS or Azure for cloud services.

### 4.2.3 Constraints

- Security: The software must include robust security features to protect against unauthorized access and data breaches
- Scalability: The software architecture should support scaling to accommodate an increasing number of devices and data volume.
- Compatibility: The software must be compatible with various operating and hardware platforms.
- Licensing: Compliance with all software licensing agreements, particularly for open-source components

### 4.2.4 Standards

- ISO/IEC 27001: Information security management standards to ensure data protection.
- IEEE 802.15.4: Standards for low-rate wireless personal area networks to ensure reliable communication protocols.
- OWASP (Open Web Application Security Project): Best practices for secure web application development

### 4.2.5 Priority

High

### 5 PERFORMANCE REQUIREMENTS

The key performance requirements for Smart Crib include real-time processing to guarantee immediate data input responses, low power consumption to extend time in service and reduce maintenance costs, and high reliability to maintain continuous operation without failures. Strong connectivity is essential for seamless communication between devices and the central server, while scalability ensures the system can handle growth in devices and data volume.

## 5.1 Real-Time Processing

### 5.1.1 DESCRIPTION

The IoT system must process and respond to data inputs in real-time to ensure timely decision-making and actions. This is crucial for applications requiring immediate updates and responses.

### 5.1.2 SOURCE

Real-time processing is driven by the need for immediate system feedback and actions in dynamic environments.

### 5.1.3 CONSTRAINTS

- Latency: The system must ensure latency is minimized
- Data Throughput: The system should handle high data throughput without significant delays or data loss.

### 5.1.4 STANDARDS

- IEEE 802.15.4: Standard for low-rate wireless personal area network ensuring reliable real-time communication
- ISO/IEC 27001: Ensuring real-time data security and integrity

### 5.1.5 PRIORITY

High

## 5.2 Low Power Consumption

### 5.2.1 DESCRIPTION

The Individual devices must operate on low power to extend battery life and reduce maintenance costs. This is particularly important for sensors and devices deployed in remote or hard-to-reach areas.

### 5.2.2 SOURCE

The requirement for low power consumption is driven by the need to minimize maintenance and operational costs, ensuring devices remain functional for extended periods without frequent battery replacements.

### 5.2.3 CONSTRAINTS

- Energy-Efficient Components: Use of low-power microcontrollers and sensors.
- Power Management: Implement power-saving modes and energy-efficient communication protocols.

### 5.2.4 STANDARDS

- Energyg Star: Standards for energy efficiency.
- IEEE 802.15.4: Ensuring low-power communication protocols

### 5.2.5 PRIORITY

High

## 5.3 Reliability

### 5.3.1 DESCRIPTION

The system must be highly reliable to ensure continuous operation without failures. This is essential for maintaining accurate and consistent performance in critical applications.
●

### 5.3.2 SOURCE

Reliability requirements originate from the need to provide consistent and dependable service, reducing the risk of operation disruptions and data inaccuracies.

### 5.3.3 CONSTRAINTS

- Redundancy: Incorporate redundant systems to handle hardware or software failures.
- Error Handling: Robust error detection and correction mechanisms.

### 5.3.4 STANDARDS

- ISO 9001: Quality management systems ensuring reliable processes.
- ISO/IEC 27001: Ensuring data reliabilit and security

### 5.3.5 PRIORITY

High

## 5.4 Connectivity

### 5.4.1 DESCRIPTION

The IoT system must maintain reliable connectivity between devices and the central server. This includes handling different types of network connections and ensuring seamless data transmission.

### 5.4.2 SOURCE

Connectivity requirements are based on the need for seamless communication and data exchange between IoT devices and the central system to provide real-time updates and control.

### 5.4.3 CONSTRAINTS

- Network Protocols: Support for multiple communication protocols e.g Wi-Fi, Bluetooth, and Zigbee
- Signal Strength: Ensure strong signal strength and coverage, especially in large or obstructed areas.

### 5.4.4 STANDARDS

- IEEE 802.11 Standards for Wi-Fi connectivity
- IEEE 802.15.4 Standards for low-rate wireless personal area networks

### 5.4.5 PRIORITY

High

## 5.5 Scalability

### 5.5.1 DESCRIPTION

Smart crib must be scalable to accommodate an increasing number of devices and data volume as the project or deployment grows.

### 5.5.2 SOURCE

Scalability requirements are driven by the need to support future growth and increased operational complexity without compromising performance

### 5.5.3 CONSTRAINTS

- Modular Architecture: Design the system with a modular architecture to facilitate easy expansion.

### 5.5.4 STANDARDS

- ISO/IEC 20000: IT service management standards ensuring scalable services

### 5.5.5 PRIORITY

High

### 6 SAFETY REQUIREMENTS

Include a header paragraph specific to your product here. Safety requirements might address items specific to your product such as: no exposure to toxic chemicals; lack of sharp edges that could harm a user; no breakable glass in the enclosure; no direct eye exposure to infrared/laser beams; packag-ing/grounding of electrical connections to avoid shock; etc.

Home automation system where a localized network has control over all devices around the house such as smart lights etc. Systems will be accessible to users through a mobile app, all systems will be able to communicate with one another and possibly function without internet connection as long as all devices are within the localized network.

### 6.1 LABORATORY EQUIPMENT LOCKOUT/TAGOUT (LOTO) PROCEDURES

### 6.1.1 DESCRIPTION

Any fabrication equipment provided used in the development of the project shall be used in accordance with OSHA standard LOTO procedures. Locks and tags are installed on all equipment items that present use hazards, and ONLY the course instructor or designated teaching assistants may remove a lock. All locks will be immediately replaced once the equipment is no longer in use.

### 6.1.2 SOURCE

CSE Senior Design laboratory policy

### 6.1.3 CONSTRAINTS

Equipment usage, due to lock removal policies, will be limited to availability of the course instructor and designed teaching assistants.

### 6.1.4 STANDARDS

Occupational Safety and Health Standards 1910.147 - The control of hazardous energy (lockout/tagout).

### 6.1.5 PRIORITY

Critical

### 6.2 NATIONAL ELECTRIC CODE (NEC) WIRING COMPLIANCE

### 6.2.1 DESCRIPTION

Any electrical wiring must be completed in compliance with all requirements specified in the National Electric Code. This includes wire runs, insulation, grounding, enclosures, over-current protection, and all other specifications.

### 6.2.2 SOURCE

CSE Senior Design laboratory policy

### 6.2.3 CONSTRAINTS

High voltage power sources, as defined in NFPA 70, will be avoided as much as possible in order to minimize potential hazards.

### 6.2.4 STANDARDS

NFPA 70

### 6.2.5 PRIORITY

Critical

### 6.3 RIA ROBOTIC MANIPULATOR SAFETY STANDARDS

### 6.3.1 DESCRIPTION

Robotic manipulators, if used, will either housed in a compliant lockout cell with all required safety interlocks, or certified as a "collaborative" unit from the manufacturer.

### 6.3.2 SOURCE

CSE Senior Design laboratory policy

### 6.3.3 CONSTRAINTS

Collaborative robotic manipulators will be preferred over non-collaborative units in order to minimize potential hazards. Sourcing and use of any required safety interlock mechanisms will be the responsi-bility of the engineering team.

### 6.3.4 STANDARDS

ANSI/RIA R15.06-2012 American National Standard for Industrial Robots and Robot Systems, RIA TR15.606-2016 Collaborative Robots

### 6.3.5 PRIORITY

Critical

### 7 MAINTENANCE & SUPPORT REQUIREMENTS

For the product we intend to roll out, below are the maintenance and support requirements we have identified:-

### 7.1 Firmware and Software Updates

### 7.1.1 Description

Regular updates to ensure security patches and feature enhancements. Over-the-Air (OTA) update capability to simplify the update process for end-users.

### 7.1.2 Source

Device manufacturers, software developers.

### 7.1.3 Constraints

- Limited bandwidth for OTA updates.

- User acceptance for automatic updates.

### 7.1.4 Standards

- IEEE 802.11 for Wi-Fi updates.
- MQTT for IoT communications.

### 7.1.5 Priority

High

### 7.2 Device Monitoring

### 7.2.1 Description

Continuous monitoring for device health and performance. Use of dashboards and alerts for proactive issue detection and resolution.

### 7.2.2 Source

Network management tools, IoT platforms.

### 7.2.3 Constraints

- Real-time data processing capabilities.
- User privacy considerations.

### 7.2.4 Standards

- ISO/IEC 27001 for information security management.
- ANSI/TIA-942 for data center management.

### 7.2.5 Priority

High

### 7.3 Network Management

### 7.3.1 Description

Ensuring reliable and stable connectivity. Regular checks and updates to network configurations and protocols.

### 7.3.2 Source

Network administrators, IoT platform providers.

### 7.3.3 Constraints

- Network infrastructure limitations.
- Interference from other devices.

### 7.3.4 Standards

- IEEE 802.3 for Ethernet.
- IEEE 802.11 for Wi-Fi.

### 7.3.5 Priority

High

### 7.4 Battery Management

### 7.4.1 Description

For battery-operated devices, regular checks and optimizations for battery life. Notifications for low battery levels and potential replacements.

### 7.4.2 Source

Device manufacturers, IoT platform providers.

### 7.4.3 Constraints

- Battery capacity and technology.
- Environmental factors affecting battery life.

### 7.4.4 Standards

- IEC 61960 for rechargeable batteries.
- UL 1642 for lithium batteries.

### 7.4.5 Priority

Medium.

### 8 OTHER REQUIREMENTS

For the product we intend to roll out, below are the other requirements we have identified:-

8.1Training and Onboarding

### 8.1.1 Description

Providing onboarding assistance for new users. Offering training sessions or tutorials to help users understand and utilize all features.

### 8.1.2 Source

Training teams, user experience designers.

### 8.1.3 Constraints

- Availability of training resources.
- User engagement and retention.

### 8.1.4 Standards

- ADDIE model for instructional design.
- ISO/IEC 40180 for IT user training.

### 8.1.5 Priority

Medium

### 8.2 Scalability and Future-Proofing

### 8.2.1 Description

Ensuring the system can scale with the number of devices and users. Planning for future upgrades and technology advancements.

### 8.2.2 Source

System architects, technology forecasters.

### 8.2.3 Constraints

- Infrastructure limitations.
- Budget for future upgrades.

### 8.2.4 Standards

- ISO/IEC 25010 for system and software quality requirements.
- TOGAF for enterprise architecture.

### 8.2.5 Priority

High

### 9 FUTURE ITEMS

### 9.1 Automatic Window Blinds Control

### 9.1.1 DESCRIPTION

This requirement involves implementing automatic control for window blinds, allowing users to open and close blinds via the SmartCrib app or based on predefined schedules and environmental conditions (e.g., sunlight intensity, time of day).

### 9.1.2 SOURCE

User feedback, market research, and competitor analysis.

### 9.1.3 CONSTRAINTS

- Budget: Limited funds to purchase and integrate motorized blinds.
- Time: Insufficient time to develop and test this feature within the project timeline.
- Skills: The team lacks expertise in motor control and integration with IoT systems.
- Technology: Need for reliable and compatible motorized blinds that can integrate with the existing SmartCrib system.

### 9.1.4 STANDARDS

IEEE 802.15.4: Standard for low-rate wireless personal area networks (LR-WPANs) applicable to Zigbee/Thread communication.
IEC 62368-1: Safety standards for electronic equipment.

### 9.1.5 PRIORITY

The priority is scaled medium as we are trying to automate lights first.

### 9.2 Smart Thermostat

### 9.2.1 DESCRIPTION

Integrating a smart thermostat with the SmartCrib system to allow users to control home heating and cooling remotely, set schedules, and receive energy usage reports.

### 9.2.2 SOURCE

Market demand analysis and user feedback.

### 9.2.3 CONSTRAINTS

- Budget: Cost constraints prevent the purchase and integration of smart thermostats.
- Time: Development and integration would extend beyond the project deadline.
- Skills: Team members do not have sufficient experience with HVAC systems and their integration with IoT.
- Feasibility Analysis: Preliminary analysis suggests significant complexity and potential compatibility issues with existing HVAC systems.

### 9.2.4 STANDARDS

ASHRAE Standards: Standards for heating, ventilation, air conditioning, and refrigeration systems.

ISO 16484-2: Building automation and control systems (BACS) standards.

### 9.2.5 PRIORITY

The priority is high as we will integrate this after automating lights.

REFERENCES

A. Yousefi, F. J. Dian, K. Somaratne “Analysis of time synchronization based on current measurement for Bluetooth Low Energy (BLE),” in IEEE IEMCON, pp. 602 – 607, Vancouver, OCT. 2017.
F. J. Dian and R. Vahidnia, “LTE IoT Technology Enhancements and Case Studies,” in IEEE Consumer Electronics Magazine, doi: 10.1109/MCE.2020.2986834.

Third Generation Partnership Project, Technical Report 36.888 v12.0.0, Study on Provision of Low-cost Machine-Type Communications (MTC) User Equipment (UEs) Based on LTE, 2013.

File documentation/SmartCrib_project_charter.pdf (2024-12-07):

### DEPARTMENT OF COMPUTER SCIENCE & ENGINEERING THE

### UNIVERSITY OF TEXAS AT ARLINGTON

### PROJECT CHARTER

# CSE 4316: SENIOR DESIGN I Summer 2024


## SMART CRIB

DON DANG

LUIS DEL RIO CARRILLO

ZAIT MARTINEZ
PRANAV UMAKANT PUJAR
Smart Crib - Summer 2024 | page 1 of 17

REVISION HISTORY

Revision | Date | Author(s) | Description
0.1 | 07/05/2024 | Don Dang | Added logo, project title, partners
0.2 | 07/05/2024 | Don Dang | Updated table of contents, revision history
1.0 | 07/05/2024 | Luis Del Rio Carrillo | Completed Problem Statement
1.1 | 07/06/2024 | Luis Del Rio Carrillo | Completed Methodology
2.1 | 07/06/2024 | Don Dang | Completed Value Proposition
2.2 | 07/06/2024 | Pranav Pujar | Completed Development Milestones
2.3 | 07/06/2024 | Zait Martinez | Completed Background
3.1 | 07/07/2024 | Zait Martinez | Completed Related Work
3.2 | 07/07/2024 | Zait Martinez | Completed System Overview
3.3 | 07/07/2024 | Don Dang | Completed Roles and Responsibilities
3.4 | 07/07/2024 | Don Dang | Completed Cost Proposal
4.1 | 07/07/2024 | Don Dang | Completed Facilities & Equipment
4.2 | 07/07/2024 | Don Dang | Completed Assumptions
4.3 | 07/07/2024 | Pranav Pujar | Completed Constraints
4.4 | 07/07/2024 | Don Dang, Pranav Pujar, Zait Martinez | Completed Risks
5.0 | 07/08/2024 | Don Dang,Pranav Pujar, Zait Martinez | Completed Documentation & Reporting

CONTENTS

1 Problem Statement | 5
2 Methodology | 5
3 Value Proposition | 5
4 Development Milestones | 5
5 Background | 6
6 Related Work | 6
7 System Overview | 7
8 Roles & Responsibilities | 8
9 Cost Proposal | 9
10 Facilities & Equipment | 10
11 Assumptions | 10
12 Constraints | 10
13 Risks | 11
14 Documentation & Reporting | 11

15 References | 17

### 1 PROBLEM STATEMENT

Numerous smart home devices come with their corresponding mobile applications, designed to be seamless, reliable, and secure. These devices transform our daily experiences, affecting how we live, work, and relax. However, the various communication and connectivity protocols often require users to navigate different administrative platforms, hindering the goal of a truly seamless experience.

### 2 METHODOLOGY

The purpose of the Smart Crib is to integrate various technologies and proprietary solutions to provide seamless interaction between different vendors of smart devices. Our approach includes developing custom devices when necessary to ensure comprehensive device administration, edge processing, and secure connections.
We plan on implementing a cross-platform mobile application that can control various hardware systems within a household. This application also needs to be able to communicate with the hardware devices (light, speakers, etc) through appropriate interfaces.

### 3 VALUE PROPOSITION

### Our system creates an environment where all your smart home devices can work together

seamlessly, allowing users to enjoy the benefits of their favorite devices on a single, unified platform. Instead of competing with other brands, we aim to complement and integrate them, fostering an ecosystem that enhances the overall smart home experience.
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

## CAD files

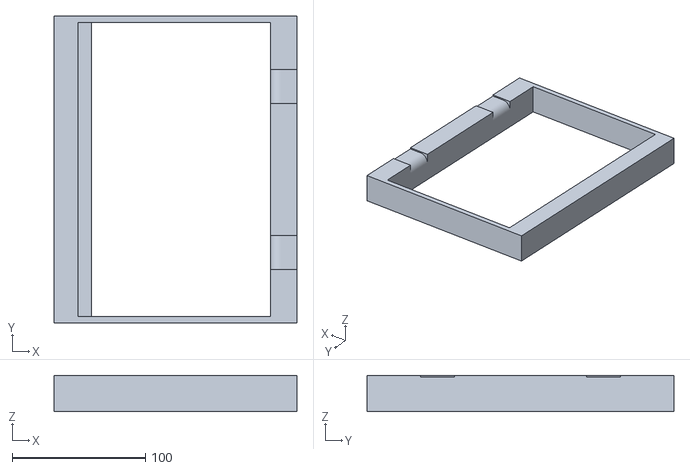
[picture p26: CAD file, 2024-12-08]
3d_designs/smart_doorlock/Door_frame.stl
182.0 x 230.0 x 27.0

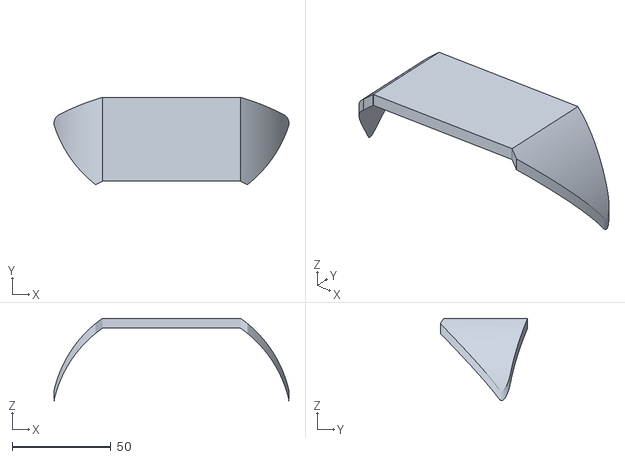
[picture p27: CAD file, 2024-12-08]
3d_designs/smart_fan/Fan_pt2.stl
119.1 x 44.2 x 41.7

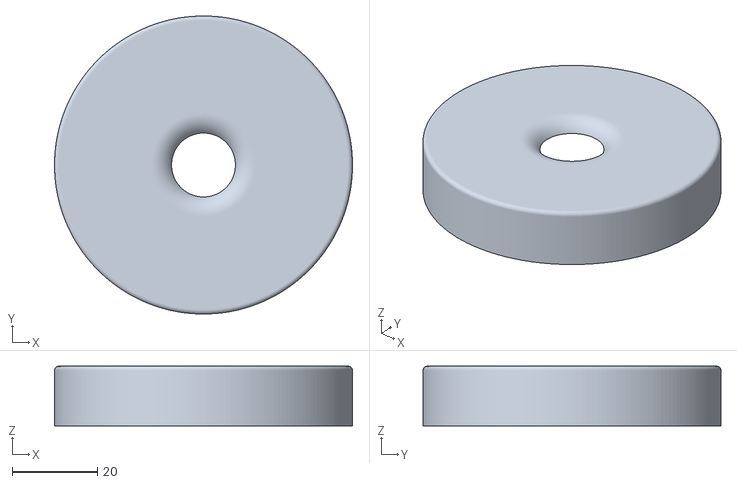
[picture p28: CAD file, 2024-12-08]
3d_designs/smart_light/Light_pt0.stl
70.0 x 70.0 x 14.0

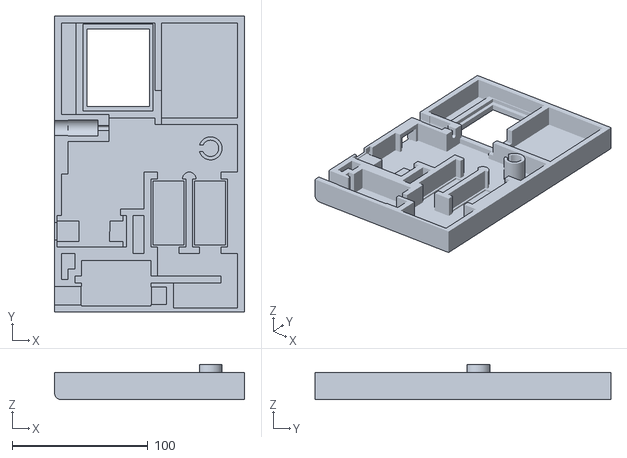
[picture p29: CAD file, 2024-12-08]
3d_designs/smart_doorlock/Door_frontplate.stl
140.0 x 218.0 x 26.0

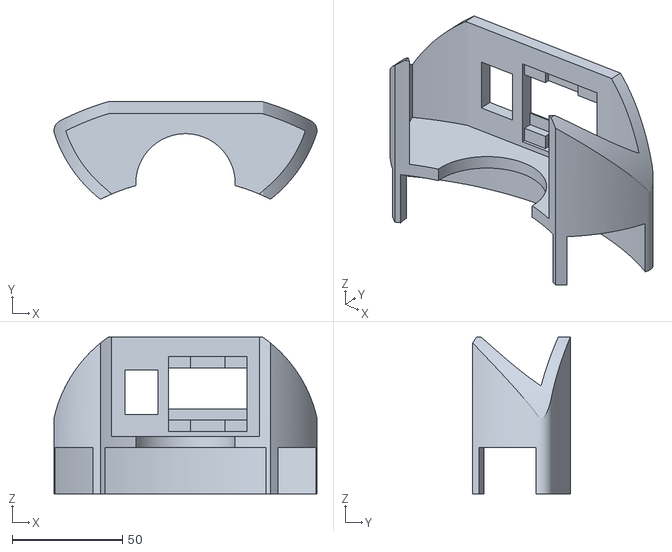
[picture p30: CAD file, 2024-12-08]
3d_designs/smart_fan/Fan_pt1.stl
119.1 x 44.2 x 71.0

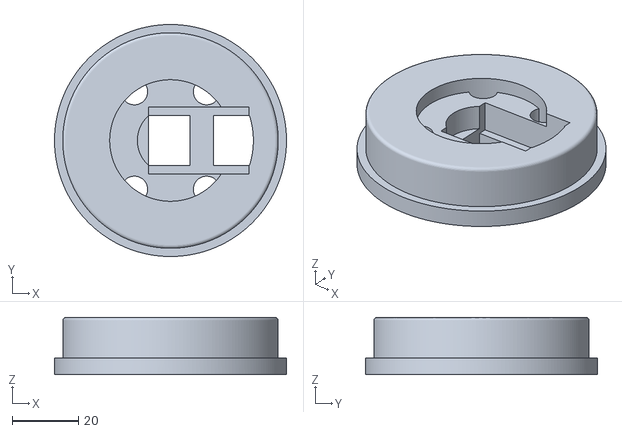
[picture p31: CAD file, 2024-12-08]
3d_designs/smart_light/Light_pt1.stl
70.0 x 70.0 x 17.3

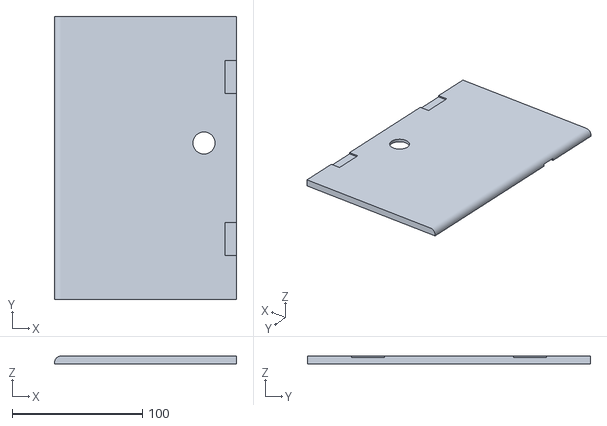
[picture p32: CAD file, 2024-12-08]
3d_designs/smart_doorlock/Door_backplate.stl
140.0 x 218.0 x 6.00

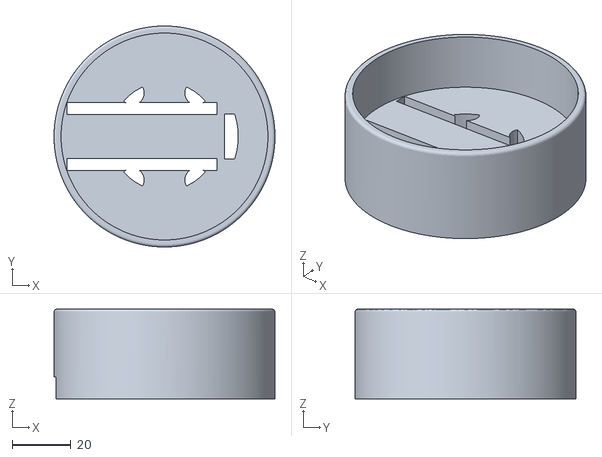
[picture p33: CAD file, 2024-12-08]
3d_designs/smart_light/Light_pt3.stl
75.0 x 75.0 x 30.5

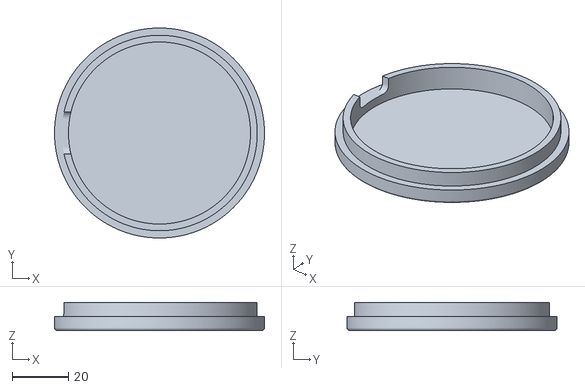
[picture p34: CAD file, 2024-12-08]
3d_designs/smart_light/Light_pt2.stl
75.0 x 75.0 x 10.0

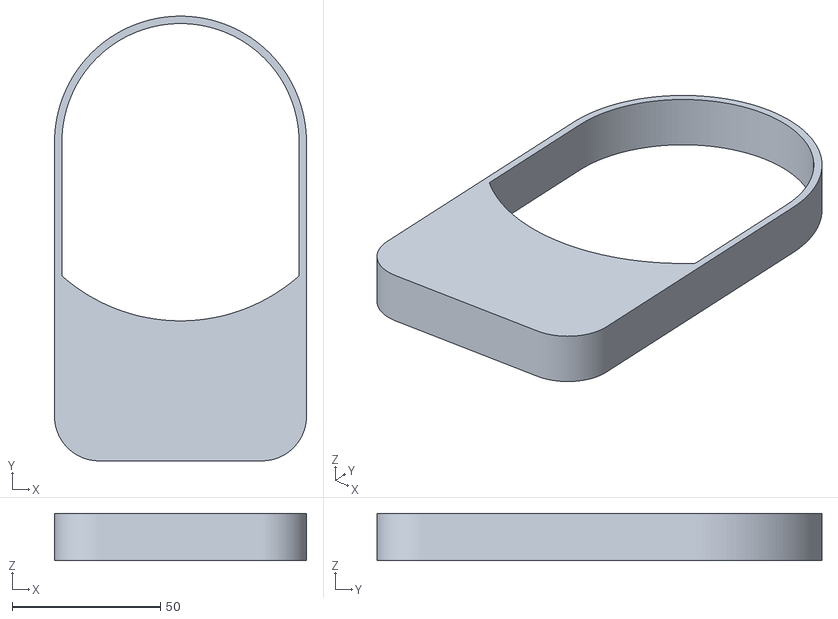
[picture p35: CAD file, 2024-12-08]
3d_designs/smart_light/Light_topcase.stl
85.0 x 150.0 x 16.0

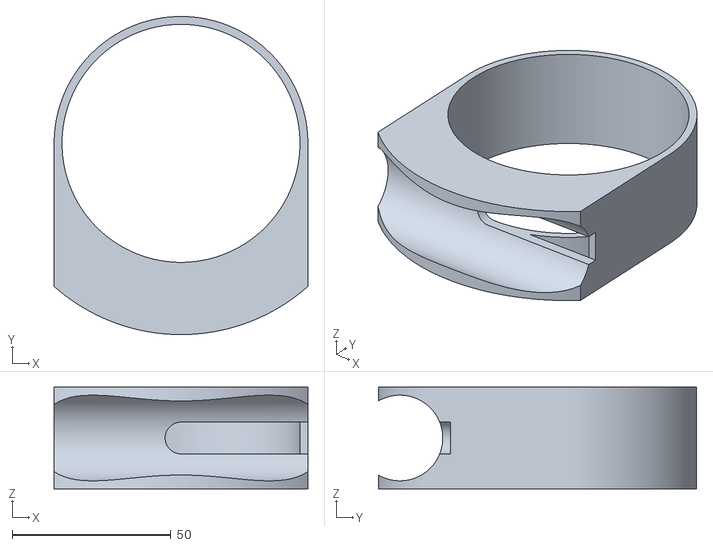
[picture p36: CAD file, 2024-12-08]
3d_designs/smart_light/Light_batteryholder.stl
80.0 x 100.2 x 32.0

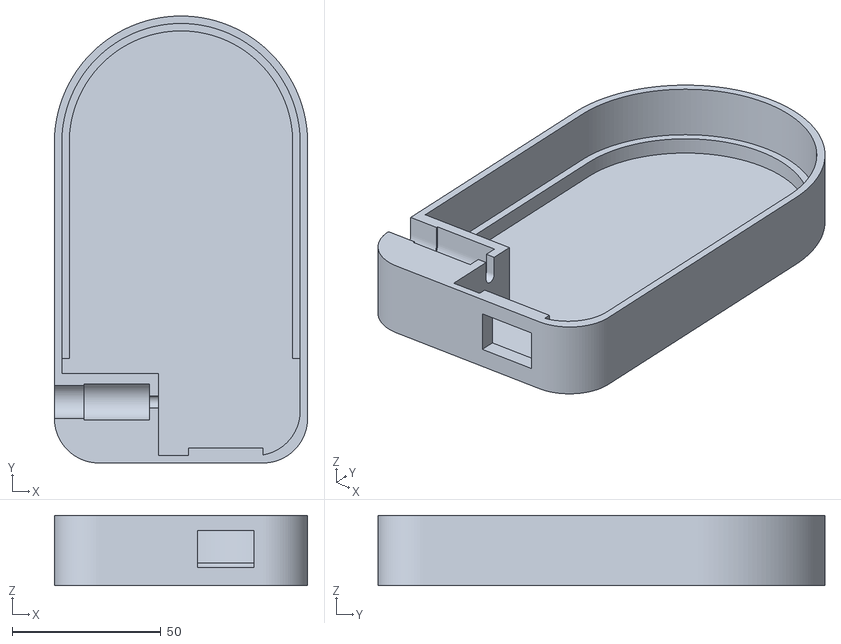
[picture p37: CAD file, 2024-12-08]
3d_designs/smart_light/Light_bottomcase.stl
85.0 x 150.0 x 23.5

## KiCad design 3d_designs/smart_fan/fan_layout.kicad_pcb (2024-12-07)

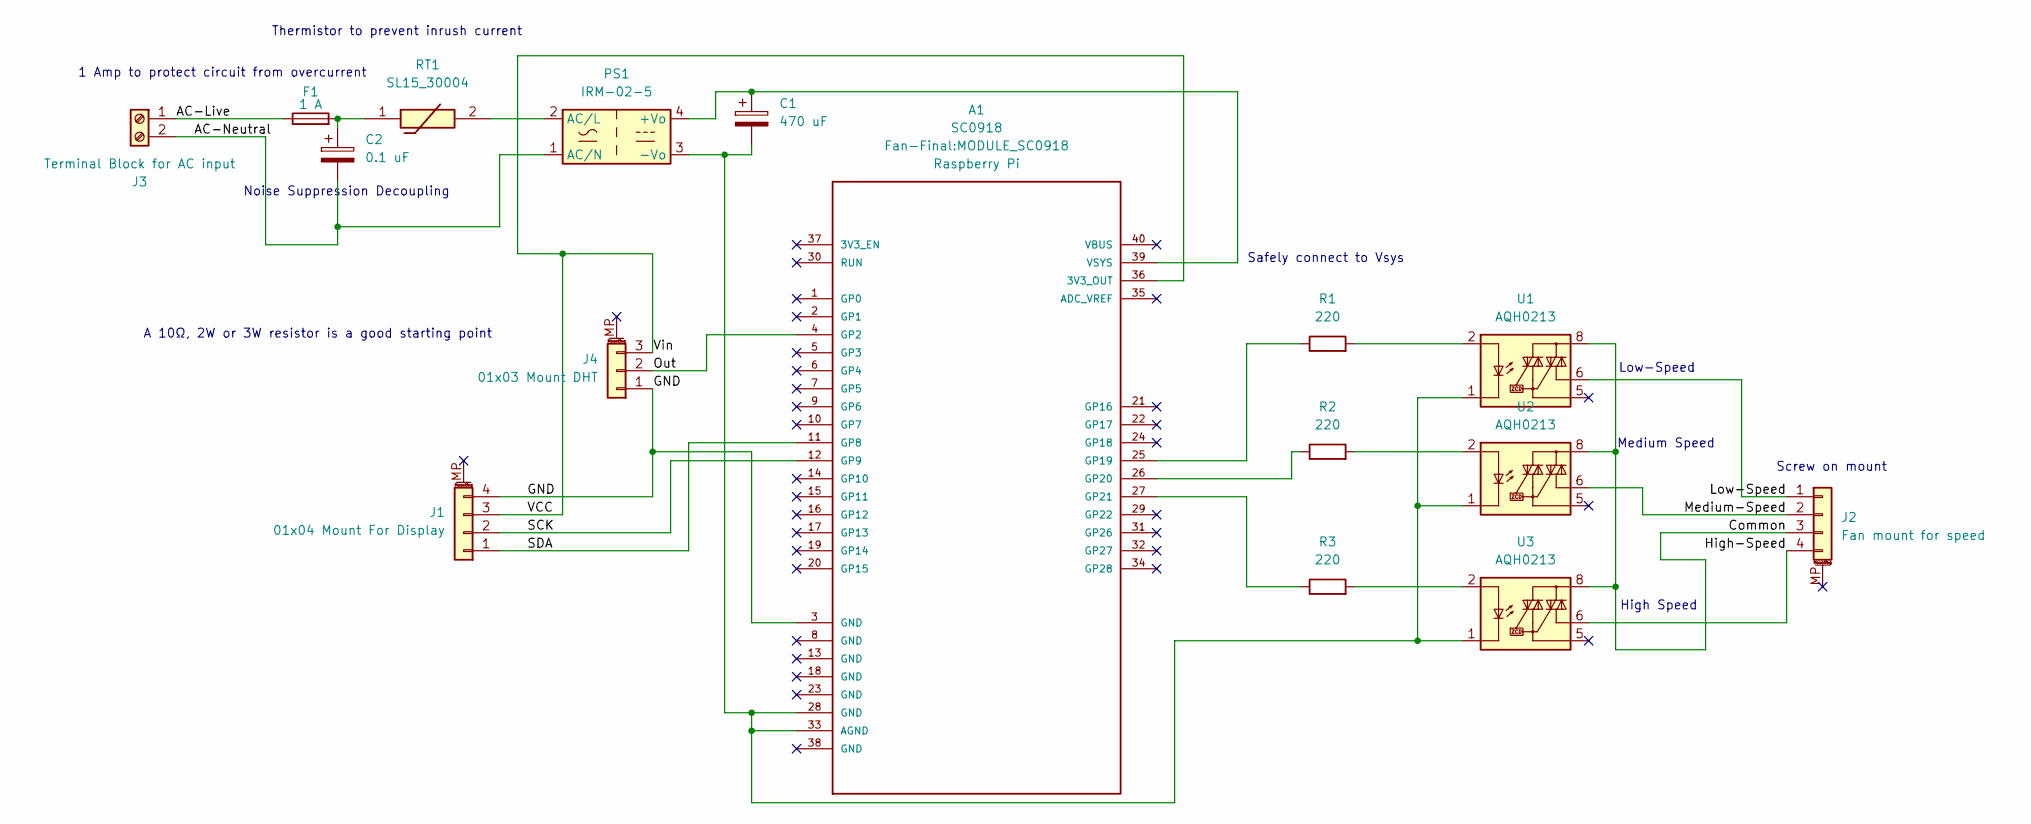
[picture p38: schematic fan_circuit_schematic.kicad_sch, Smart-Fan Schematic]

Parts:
A1: SC0918; MODULE_SC0918; PARTREV 1.6
C1: 470 uF; CP_Radial_D8.0mm_P3.50mm
C2: 0.1 uF; CP_Radial_D5.0mm_P2.50mm
F1: 1 A; Fuse_Littelfuse_395Series
J1: 01x04 Mount For Display; PinHeader_1x04_P2.54mm_Horizontal
J2: Fan mount for speed; TerminalBlock_Phoenix_MKDS-1,5-4-5.08_1x04_P5.08mm_Horizont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
J3: Terminal Block for AC input; TerminalBlock_Phoenix_MKDS-1,5-2_1x02_P5.00mm_Horizontal
J4: 01x03 Mount DHT; PinHeader_1x03_P2.54mm_Horizontal
PS1: IRM-02-5; Converter_ACDC_MeanWell_IRM-02-xx_THT
R1, R2, R3: 220; R_Axial_DIN0207_L6.3mm_D2.5mm_P7.62mm_Horizontal
RT1: SL15_30004; SL1530004; Manufacturer_Part_Number SL15 30004
U1, U2, U3: AQH0213; DIP-8-N7_W7.62mm

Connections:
/AC-Live: F1.1, J3.1
/AC-Neutral: C2.2, J3.2, PS1.1 (AC/N)
/Common: J2.3, U1.8, U2.8, U3.8
/GND: A1.3 (GND), J1.4, J4.1
/High-Speed: J2.4, U3.6
/Low-Speed: J2.1, U1.6
/Medium-Speed: J2.2, U2.6
/Out: A1.4 (GP2), J4.2
/SCK: A1.12 (GP9), J1.2
/SDA: A1.11 (GP8), J1.1
/VCC: A1.36 (3V3_OUT), J1.3, J4.3
unnamed: A1.28 (GND), A1.33 (AGND), C1.2, PS1.3 (-Vo), U1.1, U1.3, U1.4, U2.1, U2.3, U2.4, U3.1, U3.3, U3.4
unnamed: A1.25 (GP19), R1.1
unnamed: A1.26 (GP20), R2.1
unnamed: A1.27 (GP21), R3.1
unnamed: A1.39 (VSYS), C1.1, PS1.4 (+Vo)
unnamed: C2.1, F1.2, RT1.1
unnamed: PS1.2 (AC/L), RT1.2
unnamed: R1.2, U1.2
unnamed: R2.2, U2.2
unnamed: R3.2, U3.2

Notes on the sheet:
High Speed
Safely connect to Vsys
Thermistor to prevent inrush current
Screw on mount
Low-Speed
1 Amp to protect circuit from overcurrent
Medium Speed
Noise Suppression Decoupling
A 10Ω, 2W or 3W resistor is a good starting point

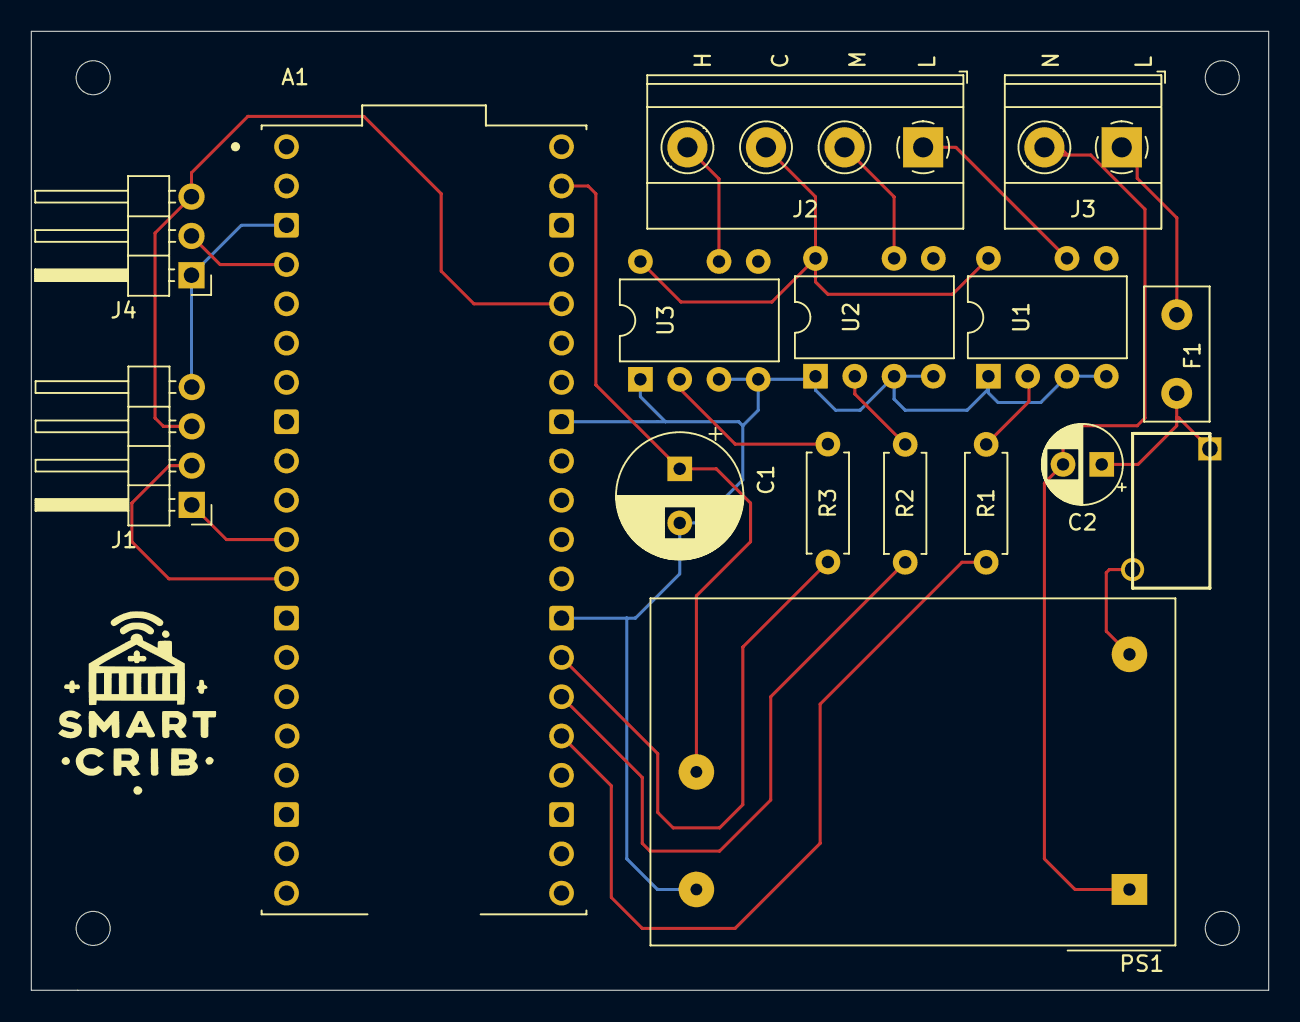
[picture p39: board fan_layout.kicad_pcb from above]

Board: 2 copper layers, 80.0 x 62.0 mm, 16 parts (0 on the bottom side), 21 nets.

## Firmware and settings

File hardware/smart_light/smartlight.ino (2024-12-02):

#include <Arduino.h>
#include <WiFi.h>
#include <HTTPClient.h>
#include <ArduinoJson.h>
#include <Adafruit_NeoPixel.h>

// WiFi credentials
const char* ssid = "iPhoneWifi";
const char* password = "password";

#define SERVER_URL "http://13.88.157.6:65432"

//LED ring light
#define PIN 15
#define NUMPIXELS 16
Adafruit_NeoPixel strip = Adafruit_NeoPixel(NUMPIXELS, PIN, NEO_GRB + NEO_KHZ800);

int total = 0;
int id = 1; // means we are a device 
int device = 1; //means we are the smartLight device
SemaphoreHandle_t stripMutex;

// Task handles
TaskHandle_t TaskSensorHandle = NULL;
TaskHandle_t TaskServerHandle = NULL;

void setup() {
    pinMode(16, INPUT);
    Serial.begin(9600);
    strip.begin();
    strip.show();

    WiFi.begin(ssid, password);
    while (WiFi.status() != WL_CONNECTED) {
        delay(500);
        Serial.print(".");
    }
    Serial.println("WiFi connected");

    stripMutex = xSemaphoreCreateMutex();
    if (stripMutex == NULL) {
        Serial.println("Failed to create mutex");
        while (true);
    }

    // Create tasks
    xTaskCreatePinnedToCore(
        TaskSensor,
        "Sensor Task",
        2048,
        NULL,
        1,
        &TaskSensorHandle,
        0
    );

    xTaskCreatePinnedToCore(
        TaskServer,
        "Server Task",
        4096,
        NULL,
        1,
        &TaskServerHandle,
        1
    );
}

void loop() {
}

// Sensor Task
void TaskSensor(void *pvParameters) {
    while (true) {
        l2();
        vTaskDelay(10 / portTICK_PERIOD_MS);
    }
}

// Server Task
void TaskServer(void *pvParameters) {
    while (true) {
        l1();
        vTaskDelay(10 / portTICK_PERIOD_MS);
    }
}

// server update fetching
void l1() {
    String data = "{\"id\": " + String(id) + ", \"device\": " + String(device) + "}";

    HTTPClient http;
    http.begin(SERVER_URL);
    http.addHeader("Content-Type", "application/json");
    int httpResponseCode = http.POST(data);

    //break down json
    if (httpResponseCode > 0) {
        String response = http.getString();

        DynamicJsonDocument doc(1024);
        deserializeJson(doc, response);
        JsonObject obj = doc.as<JsonObject>();

        if (obj.containsKey("brightness") && obj["brightness"].is<int>()) {
            total = obj["brightness"].as<int>();
            total = constrain(total, 0, 255); // Constrain brightness to 0-255

            if (xSemaphoreTake(stripMutex, portMAX_DELAY)) { // Wait for the mutex
                for (int i = 0; i < strip.numPixels(); i++) {
                    strip.setPixelColor(i, strip.Color(total, total, total));
                }
                strip.show();
                xSemaphoreGive(stripMutex); // Release the mutex
            }
        } else {
            Serial.println("Brightness not found or invalid.");
        }
    } else {
        Serial.printf("HTTP error: %d\n", httpResponseCode);
    }

    http.end();
    delay(500); // delay between server requests
}

// Sensor function
void l2() {
    byte state = digitalRead(16);

    if (state == 1) { // Motion detected
        Serial.println("Motion detected. Turning on lights...");
        if (xSemaphoreTake(stripMutex, portMAX_DELAY)) { // Wait for the mutex
            // Turn on the light strip
            for (int i = 0; i < strip.numPixels(); i++) {
                strip.setPixelColor(i, strip.Color(100, 100, 100));
            }
            strip.show();

            // Keep lights on for 5 seconds
            vTaskDelay(5000 / portTICK_PERIOD_MS);

            // Turn off the light strip
            for (int i = 0; i < strip.numPixels(); i++) {
                strip.setPixelColor(i, strip.Color(0, 0, 0));
            }
            strip.show();

            xSemaphoreGive(stripMutex); // Release the mutex
            Serial.println("Lights turned off.");
        }
    } else if (state == 0) {
        Serial.println("No motion detected.");
    }
}

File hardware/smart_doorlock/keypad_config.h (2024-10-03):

// This file contains predefined setup for various Adafruit Matrix Keypads.
#ifndef __KEYPAD_CONFIG_H__
#define __KEYPAD_CONFIG_H__

#if defined(KEYPAD_PID3844)
const byte ROWS = 4; // rows
const byte COLS = 3; // columns
// define the symbols on the buttons of the keypads
char keys[ROWS][COLS] = {{'1', '2', '3'},
                         {'4', '5', '6'},
                         {'7', '8', '9'},
                         {'*', '0', '#'}};
byte rowPins[ROWS] = {R1, R2, R3,
                      R4}; // connect to the row pinouts of the keypad
byte colPins[COLS] = {C1, C2, C3}; // connect to the column pinouts of the keypad
#endif

#if defined(KEYPAD_PID1824) || defined(KEYPAD_PID3845) || defined(KEYPAD_PID419)
const byte ROWS = 4; // rows
const byte COLS = 3; // columns
// define the symbols on the buttons of the keypads
char keys[ROWS][COLS] = {
    {'1', '2', '3'}, {'4', '5', '6'}, {'7', '8', '9'}, {'*', '0', '#'}};
byte rowPins[ROWS] = {R1, R2, R3,
                      R4};         // connect to the row pinouts of the keypad
byte colPins[COLS] = {C1, C2, C3}; // connect to the column pinouts of the
                                   // keypad
#endif

#if defined(KEYPAD_PID1332)
const byte ROWS = 1; // rows
const byte COLS = 4; // columns
// define the symbols on the buttons of the keypads
char keys[ROWS][COLS] = {
    {'1', '2', '3', '4'},
};
byte rowPins[ROWS] = {R1}; // connect to the row pinouts of the keypad
byte colPins[COLS] = {C1, C2, C3,
                      C4}; // connect to the column pinouts of the keypad
#endif

#endif

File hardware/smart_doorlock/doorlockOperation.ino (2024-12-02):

#include <Arduino.h>
#include <WiFi.h>
#include <HTTPClient.h>
#include <ArduinoJson.h>
#include "Adafruit_Keypad.h"
#include "keypad_config.h"

#define SERVER_URL "http://13.88.157.6:65432"

//keypad config specifics
#define KEYPAD_PID1824
#define R1    6
#define R2    9
#define R3    10
#define R4    11
#define C1    3
#define C2    4
#define C3    5

// actuator cont
#define relay_1 13
#define relay_2 12

// Button pin
#define button_pin 8

// connecting with iphone for demo
const char* ssid = "iPhoneWifi"; 
const char* password = "password";

int id = 1; // id as a device
int device = 3; // we are device 3doorlock
int doorlock = 0; 
int newPassword = 0;  
int appPrevstate = -1;  
int current_index = 0;


char Luis_password[5] = "1234";
char input_password[5] = "____";

Adafruit_Keypad customKeypad = Adafruit_Keypad(makeKeymap(keys), rowPins, colPins, ROWS, COLS);


// task/mutex handles
TaskHandle_t TaskKeypadHandle = NULL;
TaskHandle_t TaskServerHandle = NULL;
TaskHandle_t TaskButtonHandle = NULL;
SemaphoreHandle_t doorLockMutex;

void setup() {
  Serial.begin(9600);

  // relays
  pinMode(relay_1, OUTPUT);
  pinMode(relay_2, OUTPUT);

  // indoor btn
  pinMode(button_pin, INPUT_PULLUP);

  //connect wifi
  WiFi.begin(ssid, password);
  while (WiFi.status() != WL_CONNECTED) {
    delay(500);
    Serial.print(".");
  }
  Serial.println("WiFi connected");

  // Initialize keypad
  customKeypad.begin();

  // Create mutex
  doorLockMutex = xSemaphoreCreateMutex();

  // create/begin tasks
  xTaskCreatePinnedToCore(
    TaskKeypad,    // Task function
    "Keypad Task", // Name of the task
    2048,          // Stack size (bytes)
    NULL,          // Parameter to pass to task (none in this case)
    1,             // Priority of the task
    &TaskKeypadHandle, // Task handle
    0              // Core to run the task on (0 or 1)
  );

  xTaskCreatePinnedToCore(
    TaskServer,    
    "Server Task", 
    4096,          
    NULL,         
    1,             
    &TaskServerHandle, 
    1              
  );

  xTaskCreatePinnedToCore(
    TaskButton,   
    "Button Task", 
    2048,          
    NULL,          
    1,             
    &TaskButtonHandle, 
    0              
  );
}

void loop() {
  
}

// task for handling keypad input
void TaskKeypad(void *pvParameters) {
  while (true) {
    customKeypad.tick();  // update keypad buffer
    if (customKeypad.available()) {
      keypadEvent e = customKeypad.read();
      if (e.bit.EVENT == KEY_JUST_PRESSED) {
        handleKeypadInput((char)e.bit.KEY);  // process keypress
      }
    }
    vTaskDelay(10 / portTICK_PERIOD_MS);  // slowdown
  }
}

// Task for handling server updates
void TaskServer(void *pvParameters) {
  while (true) {
    // Prepare and send server request
    String data = "{\"id\": " + String(id) + ", \"device\": " + String(device) + "}";
    HTTPClient http;
    http.begin(SERVER_URL);
    http.addHeader("Content-Type", "application/json");

    int httpResponseCode = http.POST(data);
    if (httpResponseCode > 0) {

      // break down json
      String response = http.getString();
      DynamicJsonDocument doc(1024);
      deserializeJson(doc, response);
      JsonObject obj = doc.as<JsonObject>();

      if (obj.containsKey("doorlock") && obj["doorlock"].is<int>()) {
        doorlock = obj["doorlock"].as<int>();

        if (doorlock == 1){
          if (doorlock != appPrevstate){
            appPrevstate = 1;
            lock_door();
          }else {
            Serial.println("dont lock");
          }
        }else {
          if (doorlock != appPrevstate){
            appPrevstate = 0;
            unlock_door();
          }else {
            Serial.println("dont unlock");
          }
        }

        
      }

      //update keypad password 
      if (obj.containsKey("newPassword") && obj["newPassword"].is<int>()) {
        newPassword = obj["newPassword"].as<int>();
        sprintf(Luis_password, "%d", newPassword);
        Serial.println(Luis_password);
      }
    }
    http.end();
    vTaskDelay(250 / portTICK_PERIOD_MS);  // Wait before sending another request
  }
}

// Task for button press
void TaskButton(void *pvParameters) {
  while (true) {
    if (digitalRead(button_pin) == LOW) { //button is pressed
      if (xSemaphoreTake(doorLockMutex, portMAX_DELAY) == pdTRUE) {
        Serial.println("Button Pressed: Unlocking door");
        unlock_door();
        delay(5000);  // Keep the door unlocked for 5 seconds
        lock_door();
        xSemaphoreGive(doorLockMutex);
      }
    }
    vTaskDelay(50 / portTICK_PERIOD_MS);  // Debounce 
  }
}

// Handle keypad input logic
void handleKeypadInput(char key) {
  if (key != '*' && key != '#') {  // Password key
    if (current_index >= 4) {
      resetPassword();
      Serial.println("Password Too Long");
    } else {
      input_password[current_index] = key;
      current_index++;
      Serial.println(input_password);
    }
  } else if (key == '*') {
    resetPassword();
    Serial.println("Password Cleared");
  } else if (key == '#') {
    if (xSemaphoreTake(doorLockMutex, portMAX_DELAY) == pdTRUE) {
      checkPassword();
      xSemaphoreGive(doorLockMutex);
    }
  }
}


// Reset password entry
void resetPassword() {
  // memset(input_password, '_', sizeof(input_password));
  // current_index = 0;
  input_password[0] = '_';
  input_password[1] = '_';
  input_password[2] = '_';
  input_password[3] = '_';
  current_index = 0;

}


// Check if the entered password matches
void checkPassword() {
  if (strcmp(input_password, Luis_password) == 0) {
    Serial.println("Correct Password");
    unlock_door();
    delay(10000);  // Allow time to open door
    lock_door();
  } else {
    Serial.println("Incorrect Password");
  }
  resetPassword();
  Serial.println("Password Cleared");
}

// Lock and unlock door functions
void lock_door() {
  Serial.println("locking");
  digitalWrite(relay_1, HIGH);
  delay(5000);
  digitalWrite(relay_1, LOW);
}

void unlock_door() {
  Serial.println("unlocking");
  digitalWrite(relay_2, HIGH);
  delay(5000);
  digitalWrite(relay_2, LOW);
}

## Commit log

2024-07-28 added button and simplified ui
2024-10-01 Connected the react-native app to the smart lights, doorlock, and fan through http requests.
2024-10-03 Updated features - smart lights brightness ranging from 0 to 100 and smart fan has four settings: off, low, medium, or high.
2024-11-19 Connecting smart fan to the server
2024-11-19 Updated styles for door lock tab, settings page, and smart fan tab
2024-11-19 Refactor DoorlockScreen to add Lock and Unlock buttons and improve usability
    - Removed keypad for passcode entry in DoorlockScreen
    - Added TextInput for passcode entry
    - Implemented "Lock" and "Unlock" buttons with respective actions
    - Updated styles for Lock and Unlock buttons for distinct colors
    - Ensured passcode is cleared after performing lock/unlock actions
    - Simplified user interaction for door locking functionality
2024-11-19 moved keypad_test.ino inside arduino folder
2024-11-19 Moved smartlight.ino into arduino folder
2024-11-19 Smart Fan README.md update
2024-11-29 working Keypad Thread
2024-12-01 Updated Smart Fan component status
2024-12-02 smart fan updated for heat and cool
2024-12-02 Uploaded printed circuit board demo
2024-12-03 implemented red/blue led for cool and heat
2024-12-03 updated smart fan features
2024-12-03 smart fan demo image
2024-12-03 Smart fan PCB
2024-12-03 smart fan
2024-12-03 smart fan final pcb
2024-12-03 smart fan pcb final image
2024-12-04 smart fan layout
2024-12-07 smart fan designs
    [fan_circuit_schematic.kicad_sch, fan_layout.kicad_pcb]
2024-12-08 3d designs moved to appropriate area
    [Door_backplate.stl, Door_frame.stl, Door_frontplate.stl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]

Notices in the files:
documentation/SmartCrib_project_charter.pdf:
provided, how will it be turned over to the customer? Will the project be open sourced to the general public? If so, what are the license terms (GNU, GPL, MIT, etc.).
